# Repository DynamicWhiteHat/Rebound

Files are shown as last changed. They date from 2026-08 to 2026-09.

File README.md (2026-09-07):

# Rebound
Low-Cost Dysphagia Patch for Post-Stroke Patients

## Features:
### Core:
- ESP32S3 R8 SoC
- ADS1292 for surface electromyography (sEMG)
- AD5940 for bioimpedance analysis
- 16 MB flash with plenty of PSRAM
- Onboard battery charging
### Safety:
- 100K current limiting resistors on ADS1292
- 1K current limiting resistor and 15nF isolation capacitor on AD5940 current injection pin
- 470nF isolation capacitors on AD5940 read pins
- 2x TPD4E001 for ESD protection

## Image Gallery:
<table align="center">
  <tr>
    <td align="center">
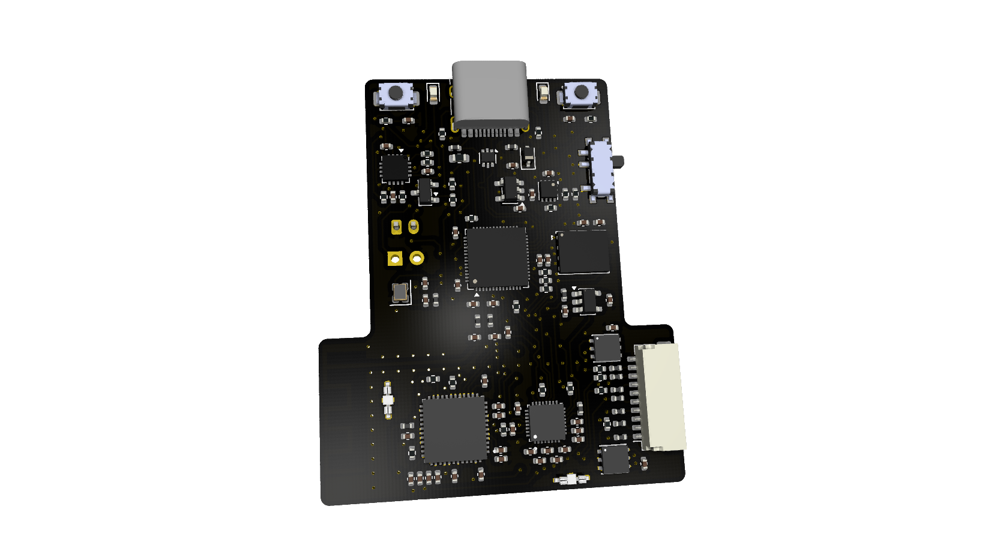
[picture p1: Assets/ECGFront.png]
      
    </td>
    <td align="center">
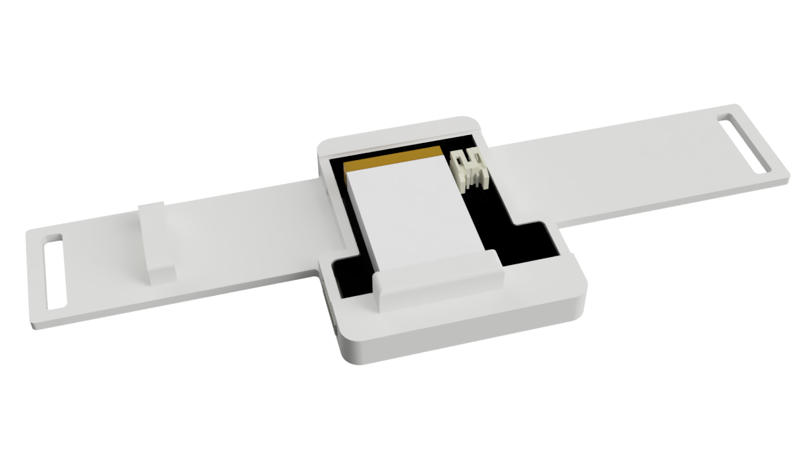
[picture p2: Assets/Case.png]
      
    </td>
  </tr>
  <tr>
    <td align="center" colspan="2">
      IMG_3539Crop
    </td>
  </tr>
</table>

## About The Project
Created after learning about the dangers that post-stroke patients can face in my EMT class, Rebound is designed to assist those who may be struggling to recognize silent aspirations, ie, when food or liquid enters the airway and lungs instead of heading to the stomach. Traumatic brain injury, Parkinson's, and ALS can also cause individuals to experience this. Gone unrecognized, silent aspirations can lead to pneumonia and potenially respiratory arrest. Rebound is meant to be worn while eating or drinking, which will enable it to constantly scan for possible signs of a silent aspiration. In the event of one, the device will immediately alert the user to prevent further complications.

## Schematic And PCB

<table align="center">
  <tr>
    <td align="center" colspan="2">
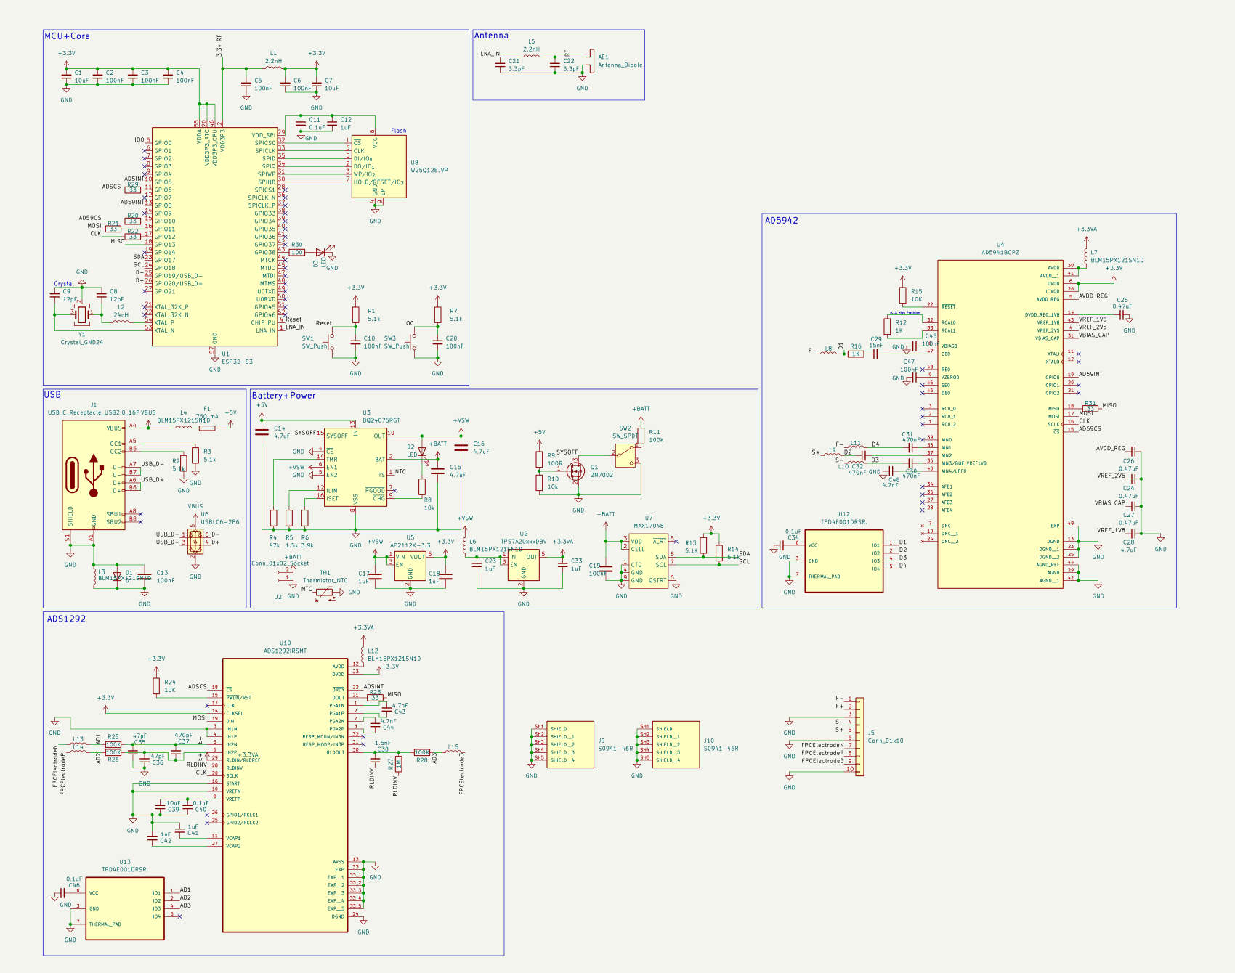
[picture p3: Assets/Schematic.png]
      
    </td>
  </tr>
  <tr>
     <td align="center">
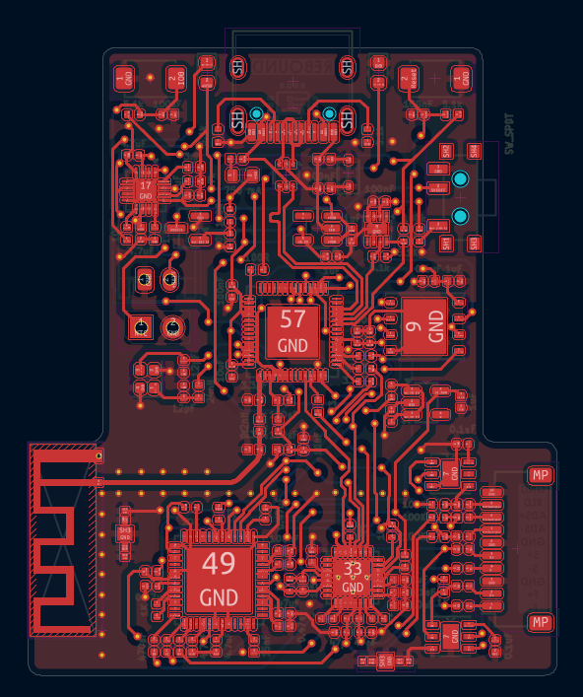
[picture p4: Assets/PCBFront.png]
      
    </td>
    <td align="center">
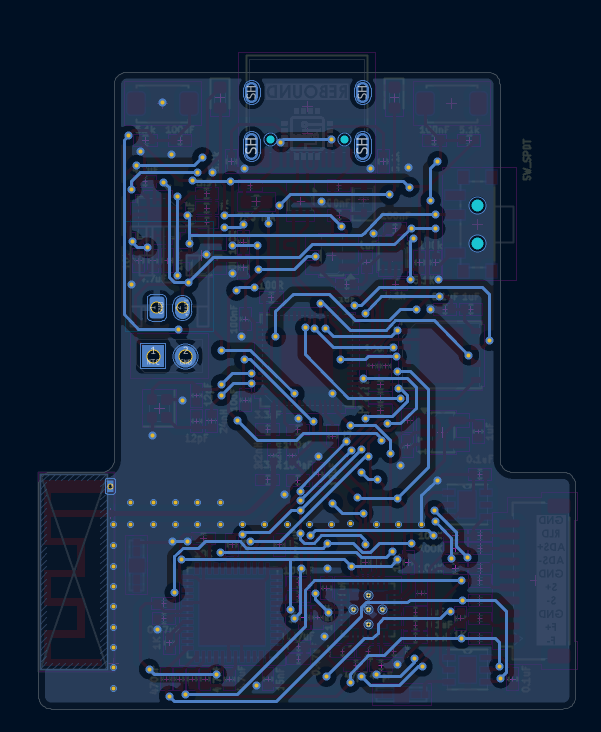
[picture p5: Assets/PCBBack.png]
      
    </td>
  </tr>
</table>

## Assembly
Once the PCB has been assembled, crimp and assemble the JST SH male connector with 10 wires. From left to right when viewed from above, the wires should be part of the 4-core strand, the 3-core strand, and another 3-core strand. Cut and strip the wires on the female electrode buttons and solder one to each of the wires not labeled GND. Then, place the PCB in the case, with the T-side pointing down. The case is meant to be worn on the backside of the neck, on a relatively flat and stiff portion to prevent the device from flexing. Plug in the JST connector and route the cables through the wire harness on the left side. Attach the RLD electrode on a bony prominence, such as the collarbone. All the following positions are based on the perspective of the user. The ADS+ electrode goes on the left half of the submental area (beneath the chin) when split vertically. The ADS- electrode goes on the right half of the submental area. The S+ electrode goes on the left sternocleidomastoid muscle. The F+ electrode goes between the S+ electrode and the Adam's Apple. The F- electrode goes on the other side of the Adam's Apple. Finally, the S- electrode goes on the right sternocleidomastoid muscle. The S+, F+, F-, and S- electrodes should all be in the same horizontal plane. Ensure none of the 7 electrodes overlap.

## How It Works
The combination of the ADS1292 and AD5940 ICs allows the device to recognize when a swallow is "off beat". Trained on data provided by a UCL study, the ADS1292 uses its sEMG abilities to monitor the activation of submental muscles that elevate the larynx to protect the airway during swallowing. Using a random forest algorithm, the device determines if the action performed was a swallow. By calculating the delta between the swallow and an object detected in the throat by the AD5940 and running it through a one-class SVM, whether or not a silent aspiration was performed can be determined.

## BOM

> [!NOTE]
> PEBA was selected for the 3D-printed case material as it is more flexible than JLC3DP's offering of TPU and biocompatible.

|Part |Quantity |Price |Link |||  | |
|---|---|---|---|---|---|---|---|
|PCB+Stencil |1 Order |$57.10 |JLCPCB Quote | | | | |
|PCB Parts |1 Order |$92.88 |See Below | | | | |
|3D Printed Case |1 |$6.13 |JLC3DP Quote | | | | |
|Multi-Core Wire |1x 3 Core, 1x 4 Core|$4.06 |https://www.aliexpress.us/item/2255800378204277.html | | | | |
|Electrodes |1 Pack of 10 |$13.85 |https://www.amazon.com/TENS-Electrodes-Premium-Replacement-Discount/dp/B01BLYJEPK/  | | | | |
|Shield Cap Holder |1 Pack of 5 |$10.50 |https://www.aliexpress.us/item/3256808839294920.html | | | | |
|Aluminum For Shield Cap |1 Sheet |$19.28 |https://www.aliexpress.us/item/3256807961227119.html | | | | |
|JST SH Pins |1 Box |$4.36 |https://www.aliexpress.us/item/3256808432090471.html | | | | |
|Electrode Buttons |1 Pack of 10 |$3.21 |https://www.aliexpress.us/item/3256806634536037.html | | | | |
|Velcro Straps |1 |$1.91 |https://www.aliexpress.us/item/3256808752475373.html | | | | |
|LiPo Battery |1 |$9.00 |https://www.amazon.com/Battery-Rechargeable-Lithium-Polymer-Connector/dp/B09F9W7Z6J/| | | | |
| |Total: |$222.28 | | | | | |
|LCSC | | | | | | | |
|Description |Quantity Needed |Mrf# |Minimum Order Qty. |Unit Price|Ext Price|LCSC# |Link |
|0.1uF |4 |CL05B104KB54PNC |100 |0.0094 |0.94 |C307331  |https://www.lcsc.com/product-detail/C307331.html  |
|0.47uF |4 |CL05A474KP5NNNC |50 |0.0211 |1.06 |C47339 |https://www.lcsc.com/product-detail/C47339.html |
|1.5k |1 |0402WGF1501TCE |100 |0.0057 |0.57 |C25867 |https://www.lcsc.com/product-detail/C25867.html |
|1.5nF |1 |GRM1555C1H152JA01D |50 |0.0278 |1.39 |C668348  |https://www.lcsc.com/product-detail/C668348.html  |
|100 |1 |0402WGF1000TCE |100 |0.0025 |0.25 |C25076 |https://www.lcsc.com/product-detail/C25076.html |
|100K |3 |RT0402BRE07100KL |50 |0.0259 |1.3 |C136979  |https://www.lcsc.com/product-detail/C136979.html  |
|100R |1 |0402WGF1000TCE |100 |0.0025 |0.25 |C25076 |https://www.lcsc.com/product-detail/C25076.html |
|100k |1 |0402WGF1003TCE |100 |0.0076 |0.76 |C25741 |https://www.lcsc.com/product-detail/C25741.html |
|100nF |11 |CL05B104KB54PNC |100 |0.0094 |0.94 |C307331  |https://www.lcsc.com/product-detail/C307331.html  |
|10K |2 |RC0402JR-0710KL |100 |0.0041 |0.41 |C60489 |https://www.lcsc.com/product-detail/C60489.html |
|10k |2 |RC0402JR-0710KL |100 |0.0041 |0.41 |C60489 |https://www.lcsc.com/product-detail/C60489.html |
|10uF |3 |CL05A106MQ5NUNC |100 |0.0257 |2.57 |C15525 |https://www.lcsc.com/product-detail/C15525.html |
|12pF |2 |CL05C120JB5NNNC |100 |0.0045 |0.45 |C26406 |https://www.lcsc.com/product-detail/C26406.html |
|15nF |1 |CC0402KRX7R9BB153 |100 |0.0039 |0.39 |C114405  |https://www.lcsc.com/product-detail/C114405.html  |
|1K |1 |4-1879208-9 |5 |0.3163 |1.58 |C306197  |https://www.lcsc.com/product-detail/C306197.html  |
|1K |1 |RT0402BRD071KL |50 |0.0271 |1.36 |C852624  |https://www.lcsc.com/product-detail/C852624.html  |
|1M |1 |0402WGF1004TCE |100 |0.007 |0.7 |C26083 |https://www.lcsc.com/product-detail/C26083.html |
|1uF |7 |CL05A105KA5NQNC |50 |0.0162 |0.81 |C52923 |https://www.lcsc.com/product-detail/C52923.html |
|2.2nH |1 |LQG15HS2N2S02D |50 |0.0131 |0.66 |C86061 |https://www.lcsc.com/product-detail/C86061.html |
|2.2nH |1 |LQW15AN2N2C10D |10 |0.0628 |0.63 |C91240 |https://www.lcsc.com/product-detail/C91240.html |
|24nH |1 |MLG1005S24NHT000 |50 |0.0078 |0.39 |C275275  |https://www.lcsc.com/product-detail/C275275.html  |
|2N7002 |1 |2N7002 |50 |0.0176 |0.88 |C8545 |https://www.lcsc.com/product-detail/C8545.html |
|3.3pF |2 |GJM1555C1H3R3WB01D |20 |0.0374 |0.75 |C88892 |https://www.lcsc.com/product-detail/C88892.html |
|3.9k |1 |RC0402FR-073K9L |100 |0.0055 |0.55 |C131467  |https://www.lcsc.com/product-detail/C131467.html  |
|33 |6 |0402WGF330JTCE |100 |0.0034 |0.34 |C25105 |https://www.lcsc.com/product-detail/C25105.html |
|4.7nF |2 |GRM1555C1H472JE01D |50 |0.02 |1 |C1518204 |https://www.lcsc.com/product-detail/C1518204.html |
|4.7nF |1 |0402B472K500NT |100 |0.0072 |0.72 |C1538 |https://www.lcsc.com/product-detail/C1538.html |
|4.7uF |4 |CL05A475MP5NRNC |50 |0.0233 |1.17 |C23733 |https://www.lcsc.com/product-detail/C23733.html |
|470nF |3 |GRM155R71C474KE01D |20 |0.0514 |1.03 |C471404  |https://www.lcsc.com/product-detail/C471404.html  |
|470pF |1 |0402B471K500NT |100 |0.0075 |0.75 |C1537 |https://www.lcsc.com/product-detail/C1537.html |
|47k |1 |0402WGF4702TCE |100 |0.0063 |0.63 |C25792 |https://www.lcsc.com/product-detail/C25792.html |
|47pF |2 |0402CG470J500NT |100 |0.0152 |1.52 |C1567 |https://www.lcsc.com/product-detail/C1567.html |
|5.1K |1 |0402WGF5101TCE |100 |0.0057 |0.57 |C25905 |https://www.lcsc.com/product-detail/C25905.html |
|5.1k |5 |0402WGF5101TCE |100 |0.0057 |0.57 |C25905 |https://www.lcsc.com/product-detail/C25905.html |
|750 mA |1 |BSMD0603-075-6V |10 |0.0672 |0.67 |C914092  |https://www.lcsc.com/product-detail/C914092.html  |
|AD5941BCPZ |1 |AD5941BCPZ |1 |20.615 |20.62 |C503573  |https://www.lcsc.com/product-detail/C503573.html  |
|ADS1292IRSMT |1 |ADS1292IRSMT |1 |9.4973 |9.5 |C89288 |https://www.lcsc.com/product-detail/C89288.html |
|AP2112K-3.3 |1 |AP2112K-3.3TRG1(MS)  |5 |0.0748 |0.37 |C22365427|https://www.lcsc.com/product-detail/C22365427.html|
|BLM15PX121SN1D |12 |BLM15PX121SN1D |50 |0.0166 |0.83 |C88970 |https://www.lcsc.com/product-detail/C88970.html |
|BQ24075RGT |1 |BQ24075RGTR |1 |1.199 |1.2 |C15464 |https://www.lcsc.com/product-detail/C15464.html |
|Conn_01x02_Socket |1 |S2B-PH-K-S(LF)(SN) |20 |0.0394 |0.79 |C173752  |https://www.lcsc.com/product-detail/C173752.html  |
|Conn_01x10 |1 |SM10B-SRSS-TB(LF)(SN)|1 |0.4986 |0.5 |C160409  |https://www.lcsc.com/product-detail/C160409.html  |
|Crystal_GND24 |1 |ECS-400-10-37-CKM-TR |1 |0.9628 |0.96 |C5246840 |https://www.lcsc.com/product-detail/C5246840.html |
|D |1 |BSD3C051V |10 |0.0661 |0.66 |C151996  |https://www.lcsc.com/product-detail/C151996.html  |
|ESP32-S3 |1 |ESP32-S3R8 |1 |3.1722 |3.17 |C2913194 |https://www.lcsc.com/product-detail/C2913194.html |
|LED |1 |LTST-C193TGKT-5A |20 |0.034 |0.68 |C12065 |https://www.lcsc.com/product-detail/C12065.html |
|LED |1 |KT-0603Y |50 |0.0107 |0.54 |C2287 |https://www.lcsc.com/product-detail/C2287.html |
|MAX17048 |1 |MAX17048G+T10 |1 |2.1836 |2.18 |C2682616 |https://www.lcsc.com/product-detail/C2682616.html |
|SW_Push |2 |TS-1088-AR02016 |10 |0.0529 |0.53 |C720477  |https://www.lcsc.com/product-detail/C720477.html  |
|SW_SPDT |1 |SSSS811101 |5 |0.149 |0.75 |C109335  |https://www.lcsc.com/product-detail/C109335.html  |
|TPD4E001DRSR. |2 |TPD4E001DRSR |2 |0.957 |1.91 |C1973310 |https://www.lcsc.com/product-detail/C1973310.html |
|TPS7A20xxxDBV |1 |TPS7A2033PDBVR |5 |0.2398 |1.2 |C2862740 |https://www.lcsc.com/product-detail/C2862740.html |
|USBLC6-2P6 |1 |USBLC6-2P6 |5 |0.2787 |1.39 |C15999 |https://www.lcsc.com/product-detail/C15999.html |
|USB_C_Receptacle_USB2.0_16P|1 |TYPE-C-31-M-12 |5 |0.1716 |0.86 |C165948  |https://www.lcsc.com/product-detail/C165948.html  |
|W25Q128JVP |1 |W25Q128JVPIQ |1 |3.7478 |3.75 |C190862  |https://www.lcsc.com/product-detail/C190862.html  |
|JST SHR-10V-S-B |1 |SHR-10V-S-B |5 |0.1598 |$0.80 |C394370  |https://www.lcsc.com/product-detail/C394370.html  |
| | | | |Subtotal  |$82.16 | | |
| | | | |Shipping  |$10.72 | | |
| | | | |Total |$92.88 | | |

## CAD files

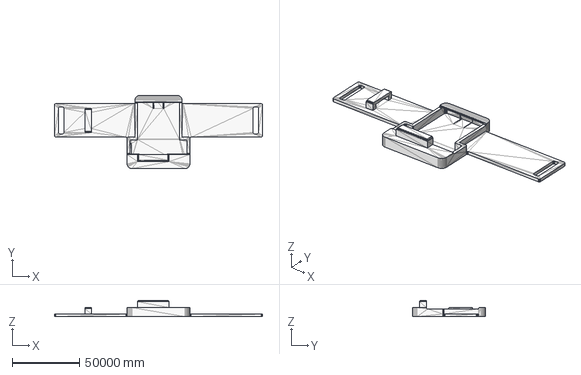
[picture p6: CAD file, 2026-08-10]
CAD/Case/STEP/Case.stp
155000.0 x 54565.0 x 12211.0 mm

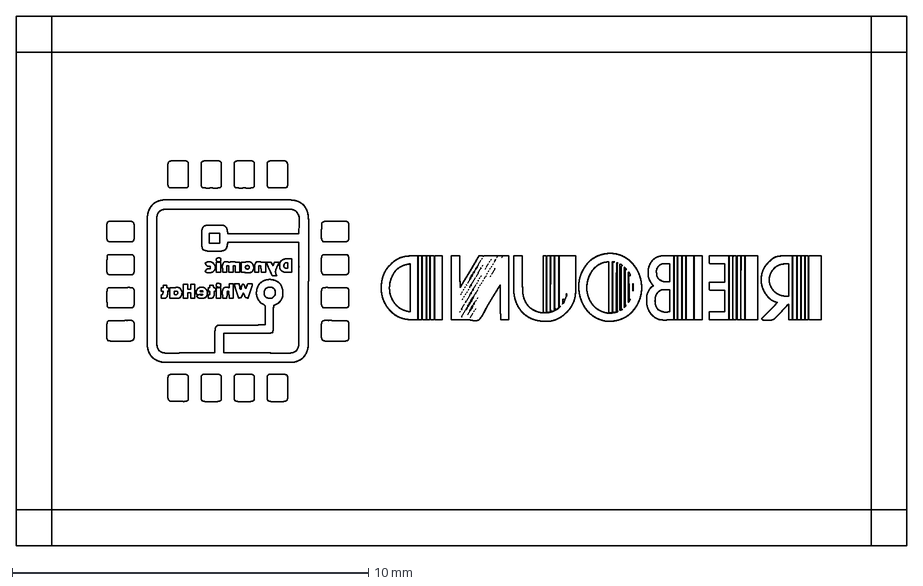
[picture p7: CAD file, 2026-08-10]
CAD/Shield Can/Aluminum.dxf
25.0 x 14.9 mm

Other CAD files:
CAD/Case/STL/Case.stl

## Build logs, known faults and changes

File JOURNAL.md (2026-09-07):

---
title: "Rebound"
author: "DynamicWhiteHat"
description: "A Low-Cost Dysphagia Patch for Post-Stroke Patients"
created_at: "2026-07-13"
---

# July 13th: Initial Research and First Schematic

**Research**

Today, I began my project by doing some research into the issue. I found that post-stroke patients can find themselves facing difficulties swallowing, a condition known as dysphagia. This can lead to *silent aspiration*, which is when food enters the airway without choking or other visible signs, and is very dangerous. As a result, patients struggling with dysphagia typically have recurring tests conducted to track their muscle condition and ability to swallow, with individual tests costing upwards of $2000. New research into surface electromyography (sEMG) shows that ICs like the ADS1292 are capable of performing high-quality sEMG analysis. Coupled with the AD5941 bioelectric measurement IC, a PCB could effectively measure a patient's capability to swallow. This measurement would be non-invasive, 24/7, and low-cost, which covers many problems associated with current testing methods. As such, I decided to create a PCB with these ICs.

**Schematic Design**

I began by creating a base schematic for an ESP-32 S3 SoC. I have created many boards with ESP-32 modules, but never just the bare SoC before. I found [this video]([url](https://www.youtube.com/watch?v=yxU_Kw2de08)) from Phil's Lab that covers exactly what I needed. I just pulled up the datasheets for the ESP-32 S3 since he used a C3, made some minor changes, and ended up with the following:

| | |
|---|---|
|  |  |
|  | |

At the core is an ESP-32 S3 R8 coupled with a 16 MB flash chip. The battery circuit, mostly taken from my [custom ZMK keyboard]([url](https://github.com/DynamicWhiteHat/Arc/)), features battery charging and USB switchover, as well as a physical power switch and a battery gauge. The antenna is a simple CLC circuit attached to an AN043 antenna, which has been tested and proven to work by Ti. I then added the AD5941 IC. This is a very sensitive analog device that is going to require special routing to ensure the signals are kept safe. I looked at reference designs online and came up with this:



Next, I set up my board for a 4-layer design, following JLCPCB's specifications for their JLC04161H-7628 stackup, which is cheap and good for impedance control. I used KiCad's built in calculator to get a track width of 0.3812 mm for a 50 ohm impedance trace for the antenna.

**Total time spent: 4 hours**

# July 15th: Final Schematic and Initial PCB Layout

**Schematic**

I had initially planned to make a separate board for the ADS1292 IC, which would be positioned higher on the neck. I got this idea from an AI generated mockup of the device. However, I later decided that placing the IC on the same board and using and FPC cable instead would help me with routing and signal concerns. I imported the IC and placed it into my schematic. Before I started making connections, I decided to add some more safety and protection lines to my AD5941 IC, such as an inductor and an ESD protection IC. This is how it looks now:



U9 is a TPD4E001 from TI, which is designed to catch any stray leakage. I also lowered the resistor value from 10K to 1K to allow the signals to be better intercepted, as previously, it would be very difficult for the IC to read signals that have gone through a 10K resistor. Finally, I also added inductors on the end of the connection, right before the line goes out to the electrode, to catch any RF/EMI signals and remove them before they reach the IC and corrupt its readings.

Next, I began working on the ADS1292 IC. Similar to how I did the AD5941, I looked up a reference design online and got to work copying it. I found the reference in the TI documentation for the IC and adjusted it to match my use case. The electrode pins on this IC are IN2N, IN2P, and RLDOUT, which connect to an FPC connector. It also has the same electrode setup, with a resistor, ESD protection, and an inductor. This is how it looks:



**PCB**

I then got to work on the PCB and did some initial layout of the IC "groups," which helps me with later placement. For example, here is the IC group layout for the AD5942:



I did that with most of the major parts, then made my Edge.Cuts for the outline. It is a rough estimate of the size and will be edited once I finish placement. I decided to place the antenna on the left side, as that will help keep RF signals away from the analog ICs, which will go on the right. This is my current PCB:



**Total time spent: 3 hours**

# July 20th: More PCB Work

I did some more PCB work today. I added the buttons in the top right and figured out where to put the power section. I decided to move the ESP32 chip down to accommodate the power stuff towards the top; that way it sort of blends in with the rest of the devices for the USB. Afterwards, I added the analog devices on the board, but then I realized that it didn't look good where it was, so I asked in Slack for help and am still awaiting a response. For now, this is where I have it.



**Total time spent: 1 hour**

# July 21st: Major PCB Work

Today I got a lot of the PCB layout done. I'm still working on the analog section, but mostly everything else is laid out. 


I began by deleting the bottom extra space after the antenna, as I didn't think that I would need to use that space, and it makes the shape much more pleasing to look at. However, I moved the antenna down a bit before that to accommodate the loss of space that I could have used earlier. I then placed some final components that I forgot about, such as the MAX17048:


I shifted around some of the surrounding ICs to make it align and look better. In the image above, you can also see that I added the connector for the battery and NTC thermistor. I originally didn't know where to put the two, as I thought they would be in the way in their current position and make routing hard. However, I moved the ESP32 and its capacitors down to make space, which fits well.

One of the largest changes I made was to swap out the ZIF connector for a 10-pin JST connector. I have decided that since this board is getting quite large, it would be better to mount it on the back of the neck and run wires to the front electrodes. I have found the following wires on AliExpress, which should work well:



Finally, I also decided to place a shield can over the analog ICs. I tried my best to move them away from RF and digital lines, but they will still end up very close to the antenna. I placed fencing vias around the antenna to block its frequencies from the analog ICs, and I plan to use Harwin shield can clips to house a custom-cut aluminum shield can to prevent any interference from the air.

**Total time spent: 3 hours**
# July 22nd: Finish Placement and Begin Routing

I finally figured out how to fit the two analog ICs. They are still very close to the antenna, and I am relying mainly on the combination of a solid ground pour, fencing vias, and a shield cap to prevent any interference to the devices. I decided to place the ADS1292 furthest from the antenna since it is the most sensitive of the two. I also had to extend the board a little bit on the bottom to allow the resistors and capacitors for the AD5940 to fit, since the IC itself is larger than the ADS1292. I flanked both sides of the JST connector with the ESD protection diodes, and that was all for placement. This is what I have for now:



I then got started with routing the PCB. It is pretty difficult since everything is so compact. I decided to start with some of the easier stuff first, like the short connections between two resistors. While routing my flash, I noticed that the ESP32 symbol in my schematic seemed off. Referencing back to my original screenshot, I realized that, at some point, the symbol switched its pins around. I don't know how that happened, but I was able to undo it and copy the original symbol. I have 41 tracks left to route. This is what I have right now:



**Total time spent: 2.5 hours**
# July  23rd: Finish PCB

I finished routing the tracks. There wasn't much in the way of routing, as I just had to make some tweaks to existing tracks and vias to make new ones fit. However, I did have to make a major change in the schematic. While routing my AD5940, I noticed that I accidentally connected the AD5940 interrupt pin to the START pin of the ADS1292. This was incorrect. Up until now, I had been relying mostly on Gemini and Claude while referencing a bit of the documentation for the two ICs since I didn't want to read 160 pages. However, once I noticed this small mistake that both AIs missed, I decided to check the wiring myself. I pulled up the pinouts of the ADS1292 first. I referenced each pin and checked its description to see what it should be connected to. For example, the VREFN pin:

For other pins, they gave solely a description of what it was for. In such cases, I searched through the datasheet to either find a connection recommendation or a typical layout of it. Once I finished all the pins, this is what I ended up with (not much changed):


There was a lot more change for the AD5940 chip. While looking through the datasheet, I found this figure for 4-wire bioimpedance measuring, which is what I am trying to do:



This was much different from my schematic, as I was using the RE0, SE0, and DE0 pins instead of AIN1-3. I copied the figure, referenced an existing board for resistor vlaues, and came up with this new design:



After that, I moved some resistors around on the board, finished routing, and ended up with this:



The white rectangle is temporary; it is to show where the shield cap goes.

**Total time spent: 3.5 hours**

# July 27th: Initial (Final?) Case

The case was a very simple design, as there can't be too much on the back of a patient's neck. This is the design I came up with:

The holes in the ends of the arms are for a Velcro strap. Initially, I had decided to just use a belt system, where the silicone would wrap around your neck and slide under itself, locking it in place. However, I realized that it had the chance of interfering with the larynx/Adam's apple location, so I decided that Velcro would be better, as it can be adjusted to fit better. 

I began the design by creating an offset of the PCB, which I exported from KiCad. The wall is 2mm thick, with a 0.2mm tolerance offset.


After I built the wall, I added two tabs, one on the top and one on the bottom, to help keep the PCB in while allowing easy removal to charge the battery. I intentionally left the USB hole covered in the design, that way, you can't charge it while the device is still attached to you, in case anything goes wrong. 



I found a 502035 400mAh battery on Amazon, which will work nicely for this design. It is thin yet holds ample power. After that, I rounded the edges and added the arms on the side, which finished my design. I added a hole for the wiring. This is my preliminary design, and I may adjust it after I actually get the PCB and Velcro.

**Total time spent: 0.75 hours**

# July 28th: Conglomerate of Activities

I began today by looking for some electrodes fit for my design. Due to their location under the chin and on the neck, the electrodes need to be very small, preferrably between 10-20mm in diameter. However, the issue with this size is that they are not *easily* commercially available. Although products like Coviden Kendall H124SG exist (shown below), they are single use and are only available from medical distributors, which incurs a high shipping fee if the order cost does not exceed $200. For this project and its budget, these electrodes are simply not good.



I continued my search on AliExpress, looking for small electrodes, pediatric electrodes, and similar items. I did not find anything good, with most of the electrodes being 30mm at the smallest. The smallest I was able to find were part of multi packs, sold as TENS electrodes. These electrodes are reusable and are primarily used for pain relief, but they work just fine for this project. Below is one of the packs:



However, I do not need all of the other sizes, and they only provide a few of the very small size. The best alternative I was able to find was these oddly shaped single-use electrodes:



I continued my search on Amazon. I mainly found more of the TENS electrode packs. After searching for a while and using the Alexa shopping assistant, I was able to find these 30mm electrodes:



I quickly made some samples out of a napkin I had, and they seem to fit. I will use these for now.

Afterwards, I moved on to the parts selection for my PCB. Many of the components on my PCB require specialized characteristics, such as a high Q factor or ceramic core. I mostly just googled for parts, with the search of "Good [component] for [circuit]," and I used the AI response. I trust the AI on this since they are pretty common parts that are used by many people. I opened the parts on LCSC, copied their LCSC number and added them to my BOM in KiCad. I used the JLCPCB tools plugin for KiCad to generate a BOM. I got tired of this and ended early, after adding most of the important parts. The rest of the components do not require any special considerations.

After that, I moved on to the code. I set up PlatformIO to serve as my codebase. This is my first time using PlatformIO. I chose it to allow me to use multiple cores of the ESP32 while keeping everything in different files, which is best done in VSCode. I watched a few videos on the math that goes into SEMG analysis. The general process is as follows:

- FFT to filter the background noise
- Bandpass filter to remove the background noise
- RMS envelope to find the average power of a frame of SEMG data

Now I have to code it.

**Total time spent: 4 hours**

# August 9th: Finished initial code and part selection

Today I finished the code and selected all my parts for the PCB. I haven't added the math processing yet, but that will require testing with the actual device, so I won't be able to do that until I have my PCB built and working. For now, I have just added printing statements. I compiled my code in PlatformIO and got this message:


This is my file structure:



Most of the AD5940 files were pulled from an Analog Devices repo online. This was great since the IC has a lot of math going on inside, which makes making a driver for it very difficult. I had to make my own drivers for the ADS1292, however. The only publicly available ones are for a custom PCB made by protocentral that has the respiration function enabled. Making a driver wasn't too difficult. The ".h" file defines all the methods and variables to be used in the implementation ".c" file, much like an interface in Java. Here is my ".h" file:



The ".c" file creates actual code for the methods. This wasn't too difficult and was done in C++. Finally, I brought everything together in main.cpp. The ADS1292 wasn't too difficult to use, since I made the drivers myself, so they were simple. However, implementing the AD5940 took a bit more work. I had to read the AD5940Main.c file to figure out what methods I needed to read the BIA values and print them. Once I got that, I compiled and got a success message. This took me about 2 days.

Next, I finished selecting my parts for the PCB. As I said earlier, all I had left were insignificant parts, ie parts that didn't have any special considerations. This was pretty quick since I used the LCSC part selection tool from the JLCPCB fab plugin for KiCad. All I have left is to get my repo ready.

**Total time spent: 5 hours**

# August 10th: Finished repository

Today I finished up the repository for the project. I began by creating my BOM.csv. To do so, I opened up my BOM from one of my past approved projects and copied its format. The good thing about the JLCPCB tools package I use in KiCad is that once I select the components, I can import that BOM into LCSC. I get this window:



LCSC will then automatically find the parts for me based on the part numbers I gave it using the KiCad package. Then, I add those parts to my cart and export the BOM, which has much more information (like pricing) than the KiCad one. I added these into my personal BOM. I was surprised by the cost of the parts, as they cost $82 before shipping. This is the most expensive LCSC order I will have placed. Afterwards, I added in the other parts required to make this project, such as the wires, electrodes, and battery. I decided to drop the silicon mold since the cheapest tub is $40. I will stick with TPU for now. This is my completed BOM:



Next, I added in the files to the repository. I like to do this in the built in VSCode web editor, available by pressing "." on the repository. This enables me to drag and drop files and arrange them into folders, without having to worry about making my own files on my laptop. I made some final changes to the case, such as increasing the clip space for the PCB, and made a render. This is what I got:



Finally, I wrote my README. I had an interestingly fun time writing this and got carried away in the wiring. However, this should help others recreate my project better. I am now ready to submit.

**Total time spent: 2 hours**

# September 2nd: Assembled PCB

I finally got all the parts today. My PCB order took quite a while to deliver because my last mile carrier was GoFo. Usually, I don't have any problems with them, but this time, my package sat around "out for delivery" for a few days before heading back to the local center. I finally got my PCB today. I decided to record a timelapse of the build, which I may post later. I began by flanking the PCB with the spare ones to lock it in place. Then I used the stencil to apply solder paste. It took me 2 tries before I got it *somewhat* well (subtle foreshadowing?)



Afterwards, I placed all the components on. This was my first time doing 0402, and although it wasn't impossible, it was very difficult to place, and I would not like to use 0402 again. Once I placed all my components, I used a hot plate to cook the PCB. 



Next, I plugged it in for the first time. However, nothing happened. My laptop didn't make a connection sound, and after testing different points on the PCB with my homemade "multimeter" (jumper wires attached to an LED), I figured I just had terrible solder joints and bridges. I now have to redo the whole assembly, and I have to figure out how to clean the ICs I only have one of.

**Total time spent: 4 hours**

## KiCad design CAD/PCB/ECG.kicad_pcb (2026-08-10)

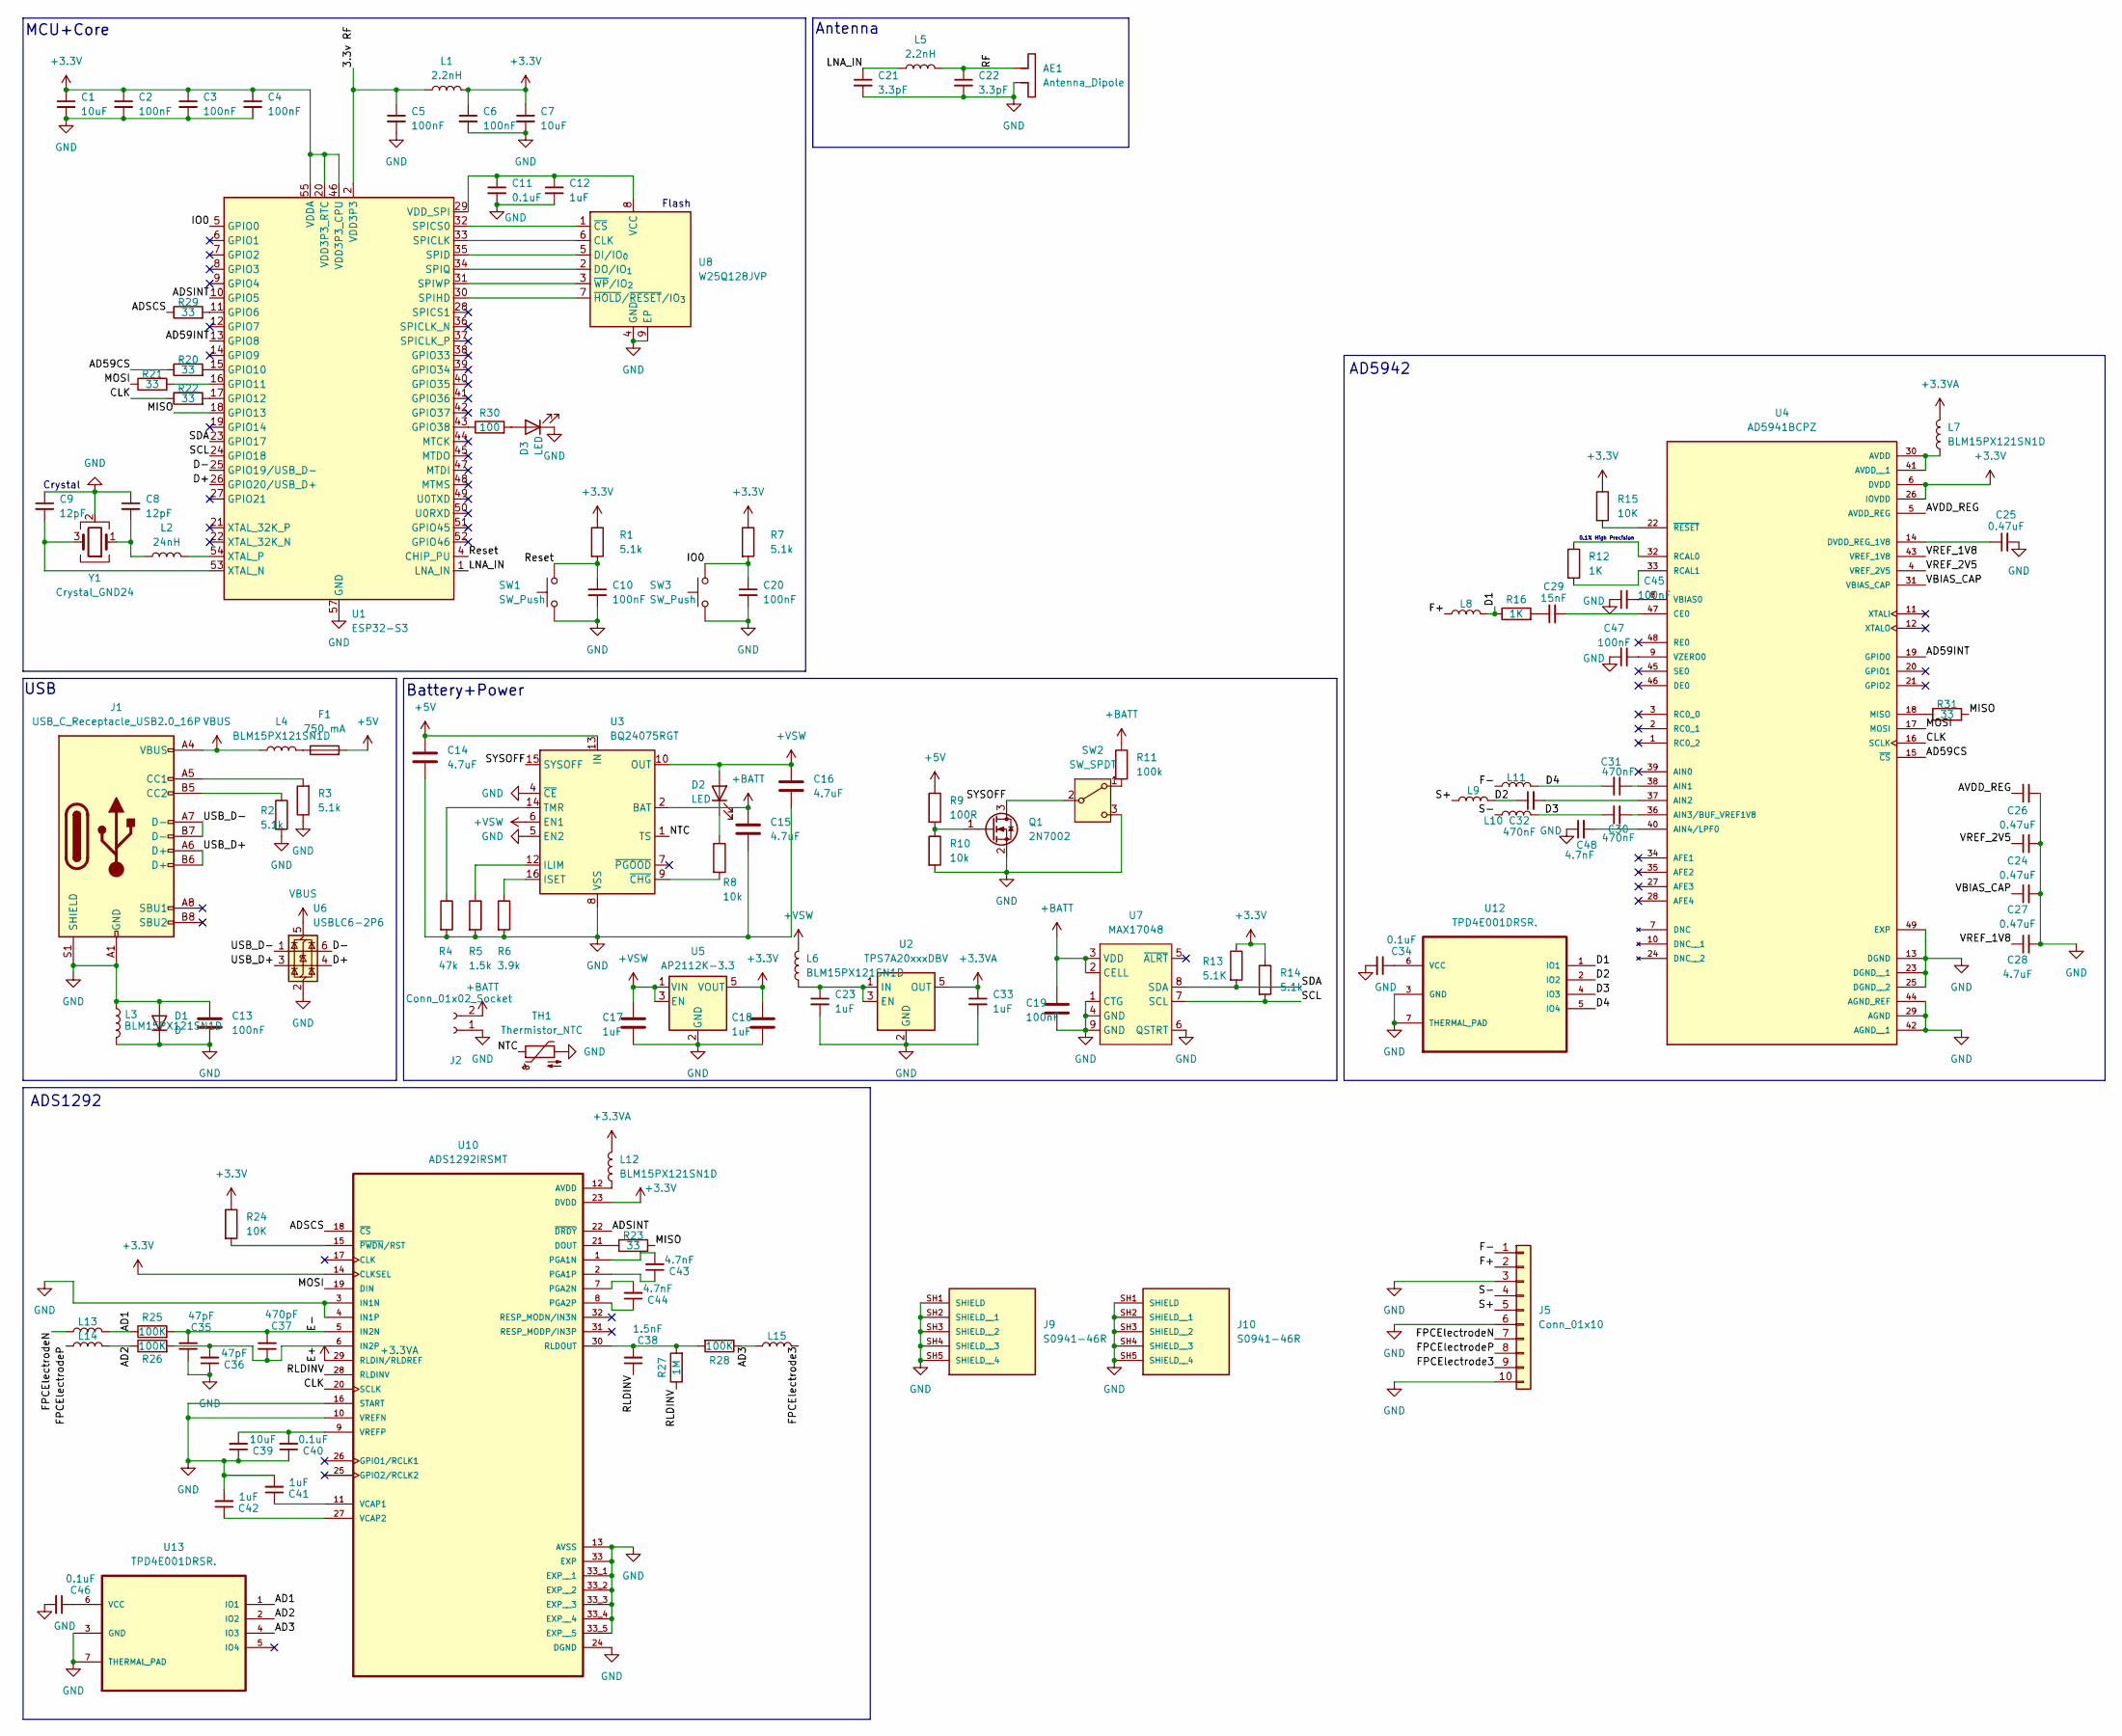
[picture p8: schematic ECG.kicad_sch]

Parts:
AE1: Antenna_Dipole; Texas_SWRA117D_2.4GHz_Left
C1, C7, C39: 10uF; C_0402_1005Metric
C2, C3, C4, C5, C6, C10, C13, C19, C20, C45, C47: 100nF; C_0402_1005Metric
C8, C9: 12pF; C_0402_1005Metric
C11, C34, C40, C46: 0.1uF; C_0402_1005Metric
C12, C17, C18, C23, C33, C41, C42: 1uF; C_0402_1005Metric
C14, C15, C16, C28: 4.7uF; C_0402_1005Metric
C21, C22: 3.3pF; C_0402_1005Metric
C24, C25, C26, C27: 0.47uF; C_0402_1005Metric
C29: 15nF; C_0402_1005Metric
C30, C31, C32: 470nF; C_0402_1005Metric
C35, C36: 47pF; C_0402_1005Metric
C37: 470pF; C_0402_1005Metric
C38: 1.5nF; C_0402_1005Metric
C43, C44, C48: 4.7nF; C_0402_1005Metric
D1: D; D_SOD-323
D2, D3: LED; LED_0603_1608Metric
F1: 750 mA; Fuse_0603_1608Metric
J1: USB_C_Receptacle_USB2.0_16P; USB_C_Receptacle_HRO_TYPE-C-31-M-12
J2: Conn_01x02_Socket; JST_PH_S2B-PH-K_1x02_P2.00mm_Horizontal
J5: Conn_01x10; JST_SH_SM10B-SRSS-TB_1x10-1MP_P1.00mm_Horizontal
J9, J10: S0941-46R; HARWIN_S0941-46R; PARTREV 4
L1, L5: 2.2nH; L_0402_1005Metric
L2: 24nH; L_0402_1005Metric
L3, L4, L6, L7, L8, L9, L10, L11, L12, L13, L14, L15: BLM15PX121SN1D; L_0402_1005Metric
Q1: 2N7002; SOT-23
R1, R2, R3, R7, R14: 5.1k; R_0402_1005Metric
R4: 47k; R_0402_1005Metric
R5: 1.5k; R_0402_1005Metric
R6: 3.9k; R_0402_1005Metric
R8, R10: 10k; R_0402_1005Metric
R9: 100R; R_0402_1005Metric
R11: 100k; R_0402_1005Metric
R12, R16: 1K; R_0402_1005Metric
R13: 5.1K; R_0402_1005Metric
R15, R24: 10K; R_0402_1005Metric
R20, R21, R22, R23, R29, R31: 33; R_0402_1005Metric
R25, R26, R28: 100K; R_0402_1005Metric
R27: 1M; R_0402_1005Metric
R30: 100; R_0402_1005Metric
SW1, SW3: SW_Push; SW_TS-1088-AR02016
SW2: SW_SPDT; SW_SSSS811101
TH1: Thermistor_NTC; PinHeader_1x02_P2.54mm_Vertical
U1: ESP32-S3; QFN-56-1EP_7x7mm_P0.4mm_EP4x4mm
U2: TPS7A20xxxDBV; SOT-23-5
U3: BQ24075RGT; VQFN-16-1EP_3x3mm_P0.5mm_EP1.6x1.6mm
U4: AD5941BCPZ; QFN50P700X700X80-49N; PARTREV B
U5: AP2112K-3.3; SOT-23-5
U6: USBLC6-2P6; SOT-666
U7: MAX17048; DFN-8-1EP_2x2mm_P0.5mm_EP0.8x1.6mm
U8: W25Q128JVP; WSON-8-1EP_6x5mm_P1.27mm_EP3.4x4.3mm
U10: ADS1292IRSMT; QFN40P400X400X100-33N
U12, U13: TPD4E001DRSR.; SON95P315X315X80-7N; MPN TPD4E001DRSR.
Y1: Crystal_GND24; Crystal_SMD_2016-4Pin_2.0x1.6mm

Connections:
+3.3V: C1.1, C2.1, C3.1, C4.1, C6.1, C7.1, C18.1, L1.2, R1.1, R7.1, R13.1, R14.1, R15.1, R24.1, U1.20 (VDD3P3_RTC), U1.46 (VDD3P3_CPU), U1.55 (VDDA), U1.56 (VDDA), U4.6 (DVDD), U4.26 (IOVDD), U5.5 (VOUT), U10.14 (CLKSEL), U10.23 (DVDD)
+3.3VA: C33.1, L7.2, L12.2, U2.5 (OUT), U10.29 (RLDIN/RLDREF)
+5V: C14.1, F1.2, R9.1, U3.13 (IN)
+BATT: C15.1, C19.1, J2.2, R11.1, U3.2 (BAT), U3.3 (BAT), U7.2 (CELL), U7.3 (VDD)
+VSW: C16.1, C17.1, D2.2 (A), L6.2, U3.6 (EN1), U3.10 (OUT), U3.11 (OUT), U5.1 (VIN), U5.3 (EN)
/3.3v RF: C5.1, L1.1, U1.2 (VDD3P3), U1.3 (VDD3P3)
/AD1: L13.2, R25.1, U13.1 (IO1)
/AD2: L14.2, R26.1, U13.2 (IO2)
/AD3: L15.1, R28.1, U13.4 (IO3)
/AD59CS: R20.1, U4.15 (~CS)
/AD59INT: U1.13 (GPIO8), U4.19 (GPIO0)
/ADSCS: R29.1, U10.18 (~CS)
/ADSINT: U1.10 (GPIO5), U10.22 (~DRDY)
/AVDD_REG: C26.1, U4.5 (AVDD_REG)
/CLK: R22.1, U4.16 (SCLK), U10.20 (SCLK)
/D1: L8.2, R16.1, U12.1 (IO1)
/D2: C32.1, L9.2, U12.2 (IO2)
/D3: C30.1, L10.2, U12.4 (IO3)
/D4: C31.2, L11.2, U12.5 (IO4)
/D+: U1.26 (GPIO20/USB_D+), U6.4 (I/O2)
/D-: U1.25 (GPIO19/USB_D-), U6.6 (I/O1)
/E+: C36.2, C37.1, R26.2, U10.6 (IN2P)
/E-: C35.2, C37.2, R25.2, U10.5 (IN2N)
/F+: J5.2, L8.1
/F-: J5.1, L11.1
/FPCElectrode3: J5.9, L15.2
/FPCElectrodeN: J5.7, L13.1
/FPCElectrodeP: J5.8, L14.1
/IO0: C20.1, R7.2, SW3.2, U1.5 (GPIO0)
/LNA_IN: C21.1, L5.1, U1.1 (LNA_IN)
/MISO: R23.2, R31.2, U1.18 (GPIO13)
/MOSI: R21.1, U4.17 (MOSI), U10.19 (DIN)
/NTC: TH1.1, U3.1 (TS)
/RF: AE1.1, C22.1, L5.2; also elsewhere on the board
/RLDINV: C38.1, R27.1, U10.28 (RLDINV)
/Reset: C10.1, R1.2, SW1.2, U1.4 (CHIP_PU)
/S+: J5.5, L9.1
/S-: J5.4, L10.1
/SCL: R14.2, U1.24 (GPIO18), U7.7 (SCL)
/SDA: R13.2, U1.23 (GPIO17), U7.8 (SDA)
/SYSOFF: Q1.3 (D), SW2.2 (B), U3.15 (SYSOFF)
/USB_D+: J1.A6 (D+), J1.B6 (D+), U6.3 (I/O2)
/USB_D-: J1.A7 (D-), J1.B7 (D-), U6.1 (I/O1)
/VBIAS_CAP: C27.1, U4.31 (VBIAS_CAP)
/VREF_1V8: C28.1, U4.43 (VREF_1V8)
/VREF_2V5: C24.1, U4.4 (VREF_2V5)
GND: AE1.2, C1.2, C2.2, C3.2, C4.2, C5.2, C6.2, C7.2, C8.1, C9.1, C10.2, C11.2, C12.2, C13.1, C13.2, C14.2, C15.2, C16.2, C17.2, C18.2, C19.2, C20.2, C21.2, C22.2, C23.2, C24.2, C25.2, C26.2, C27.2, C28.2, C33.2, C34.2, C35.1, C36.1, C39.1, C40.1, C41.2, C42.2, C45.1, C46.2, C47.1, C48.1, D1.1 (K), D1.2 (A), D3.1 (K), J1.A1 (GND), J1.A12 (GND), J1.B1 (GND), J1.B12 (GND), J1.S1 (SHIELD), J2.1, J5.3, J5.6, J5.10, J9.SH1 (SHIELD), J9.SH2 (SHIELD__1), J9.SH3 (SHIELD__2), J9.SH4 (SHIELD__3), J9.SH5 (SHIELD__4), J10.SH1 (SHIELD), J10.SH2 (SHIELD__1), J10.SH3 (SHIELD__2), J10.SH4 (SHIELD__3), J10.SH5 (SHIELD__4), L3.1, L3.2, Q1.2 (S), R2.2, R3.1, R4.2, R5.2, R6.2, R10.2, SW1.1, SW2.3 (C), SW3.1, TH1.2, U1.57 (GND), U2.2 (GND), U3.4 (~CE), U3.5 (EN2), U3.8 (VSS), U3.17 (VSS), U4.13 (DGND), U4.23 (DGND__1), U4.25 (DGND__2), U4.29 (AGND), U4.42 (AGND__1), U4.44 (AGND_REF), U4.49 (EXP), U5.2 (GND), U6.2 (GND), U7.1 (CTG), U7.4 (GND), U7.6 (QSTRT), U7.9 (GND), U8.4 (GND), U8.9 (EP), U10.3 (IN1N), U10.4 (IN1P), U10.10 (VREFN), U10.13 (AVSS), U10.16 (START), U10.24 (DGND), U10.33 (EXP), U10.33_1 (EXP__1), U10.33_2 (EXP__2), U10.33_3 (EXP__3), U10.33_4 (EXP__4), U10.33_5 (EXP__5), U12.3 (GND), U12.7 (THERMAL_PAD), U13.3 (GND), U13.7 (THERMAL_PAD), Y1.2 (G), Y1.4 (G); also elsewhere on the board
unnamed: C8.2, L2.1, Y1.1
unnamed: C29.1, R16.2
unnamed: D2.1 (K), R8.1
unnamed: D3.2 (A), R30.2
unnamed: F1.1, L4.2
unnamed: J1.A5 (CC1), R3.2
unnamed: J1.B5 (CC2), R2.1
unnamed: Q1.1 (G), R9.2, R10.1
unnamed: R11.2, SW2.1 (A)
unnamed: R29.2, U1.11 (GPIO6)
unnamed: R20.2, U1.15 (GPIO10)
unnamed: R21.2, U1.16 (GPIO11)
unnamed: R22.2, U1.17 (GPIO12)
unnamed: R30.1, U1.43 (GPIO38)
unnamed: U1.33 (SPICLK), U8.6 (CLK)
unnamed: U1.32 (SPICS0), U8.1 (~CS)
unnamed: U1.35 (SPID), U8.5 (DI/IO_{0})
unnamed: U1.30 (SPIHD), U8.7 (~HOLD/~RESET/IO_{3})
unnamed: U1.34 (SPIQ), U8.2 (DO/IO_{1})
unnamed: U1.31 (SPIWP), U8.3 (~WP/IO_{2})
unnamed: C11.1, C12.1, U1.29 (VDD_SPI), U8.8 (VCC)
unnamed: C9.2, U1.53 (XTAL_N), Y1.3
unnamed: L2.2, U1.54 (XTAL_P)
unnamed: C23.1, L6.1, U2.1 (IN), U2.3 (EN)
unnamed: R5.1, U3.12 (ILIM)
unnamed: R6.1, U3.16 (ISET)
unnamed: R4.1, U3.14 (TMR)
unnamed: R8.2, U3.9 (~CHG)
unnamed: C31.1, U4.38 (AIN1)
unnamed: C32.2, U4.37 (AIN2)
unnamed: C30.2, U4.36 (AIN3/BUF_VREF1V8)
unnamed: C48.2, U4.40 (AIN4/LPF0)
unnamed: L7.1, U4.30 (AVDD), U4.41 (AVDD__1)
unnamed: C29.2, U4.47 (CE0)
unnamed: C25.1, U4.14 (DVDD_REG_1V8)
unnamed: R31.1, U4.18 (MISO)
unnamed: R12.1, U4.32 (RCAL0)
unnamed: R12.2, U4.33 (RCAL1)
unnamed: C45.2, U4.8 (VBIAS0)
unnamed: C47.2, U4.9 (VZERO0)
unnamed: R15.2, U4.22 (~RESET)
unnamed: L12.1, U10.12 (AVDD)
unnamed: R23.1, U10.21 (DOUT)
unnamed: C43.2, U10.1 (PGA1N)
unnamed: C43.1, U10.2 (PGA1P)
unnamed: C44.2, U10.7 (PGA2N)
unnamed: C44.1, U10.8 (PGA2P)
unnamed: C38.2, R27.2, R28.2, U10.30 (RLDOUT)
unnamed: C41.1, U10.11 (VCAP1)
unnamed: C42.1, U10.27 (VCAP2)
unnamed: C39.2, C40.2, U10.9 (VREFP)
unnamed: R24.2, U10.15 (~PWDN/RST)
unnamed: C34.1, U12.6 (VCC)
unnamed: C46.1, U13.6 (VCC)
VBUS: J1.A4 (VBUS), J1.A9 (VBUS), J1.B4 (VBUS), J1.B9 (VBUS), L4.1, U6.5 (VBUS)

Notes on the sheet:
ADS1292
Crystal
Flash
AD5942
MCU+Core
0.1% High Precision
Battery+Power
Antenna
USB

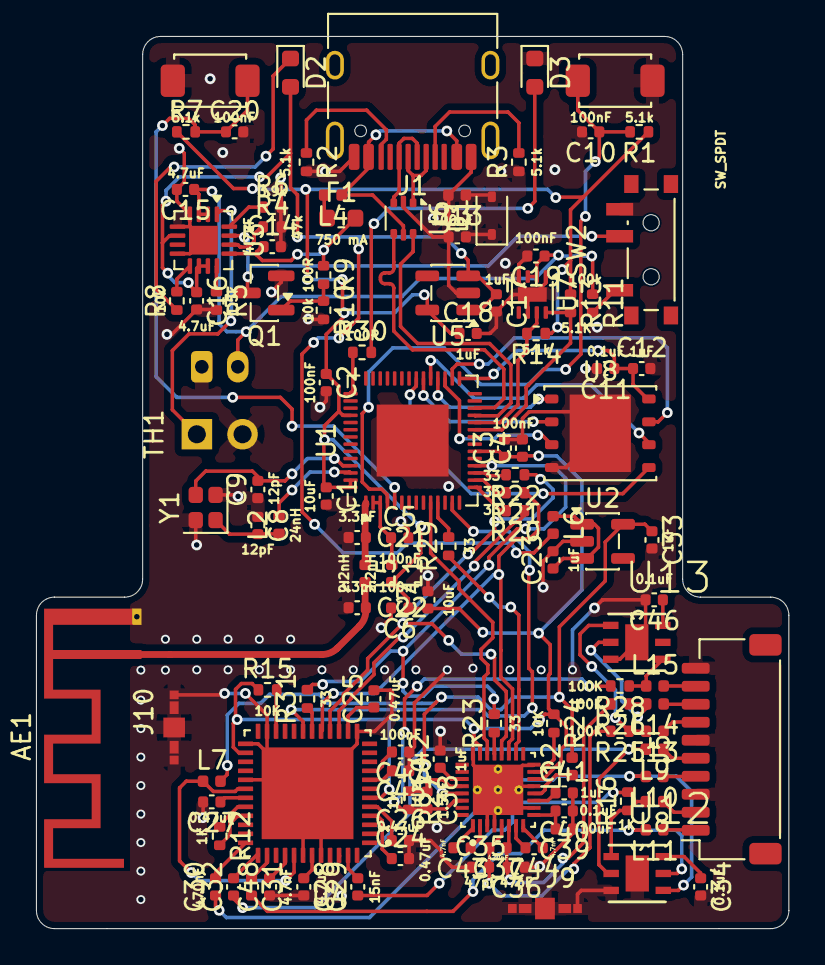
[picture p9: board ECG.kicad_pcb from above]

Board: 4 copper layers, 41.8 x 49.6 mm, 119 parts (1 on the bottom side), 102 nets.

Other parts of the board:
AE1#2: Antenna_Dipole; Texas_SWRA117D_2.4GHz_Left

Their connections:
/RF: AE1#2.1; also elsewhere on the board
GND: AE1#2.2; also elsewhere on the board

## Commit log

2026-07-27 Add design notes for initial case on July 27th
    Documented the design process and considerations for the initial case, including material choices and adjustments made for usability.
2026-08-01 Update JOURNAL with electrode search and PCB design notes
    Documented the search for electrodes and PCB parts selection process, including findings from Amazon and AliExpress. Added details on the use of PlatformIO for coding and SEMG analysis methods.
2026-08-10 Update JOURNAL.md with coding and part selection details
    Documented progress on coding and part selection for PCB, including challenges faced with driver implementation and part selection tool usage.
2026-08-10 Update journal with progress on PCB and driver coding
    Documented progress on PCB code and part selection, including challenges with driver implementation for ADS1292 and AD5940.
2026-08-10 Final Changes
    [Aluminum.dxf, BOM-ECG.csv, Case.stl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]
2026-08-10 Fix BOM section formatting in README
    Updated the BOM section formatting in README.md.
2026-08-10 Finish project repository and update BOM
    Completed the project repository by creating BOM.csv, importing parts from LCSC, and adding necessary files. Made final adjustments to the case and wrote the README for project submission.
2026-08-10 Revise BOM with new total and additional item
    Updated total cost in BOM section and added 3D printed case.
2026-08-10 Fix spelling and formatting in README.md
    Corrected spelling of 'algorithm' and adjusted formatting in the BOM section.
2026-08-10 Added New BOM
    [Rebound BOM.csv]
2026-08-10 Update README with BOM and material selection details
    Added note about material selection for 3D-printed case and updated BOM.
2026-08-13 Rename Rebound BOM.csv to BOM.csv
    [BOM.csv]
2026-09-07 Update JOURNAL.md with PCB assembly details
    Documented the assembly of the PCB, including challenges faced and time spent on the process.
2026-09-07 Update README with core features and safety details
    Added safety features and core specifications for the device.
